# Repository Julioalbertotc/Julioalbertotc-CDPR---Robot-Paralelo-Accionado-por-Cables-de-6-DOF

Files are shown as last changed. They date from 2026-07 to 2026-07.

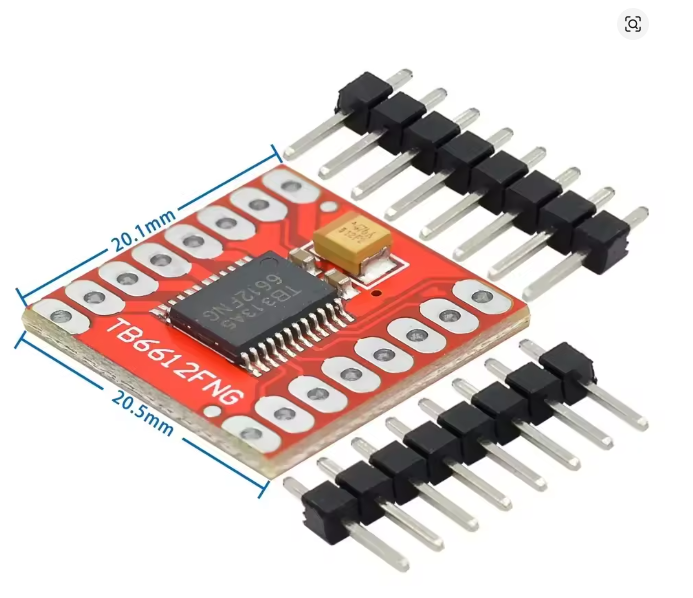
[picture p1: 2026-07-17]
robot de cables/Documentation_Parts/Documentation_Bridge-H/Measures_Bridge-H.png

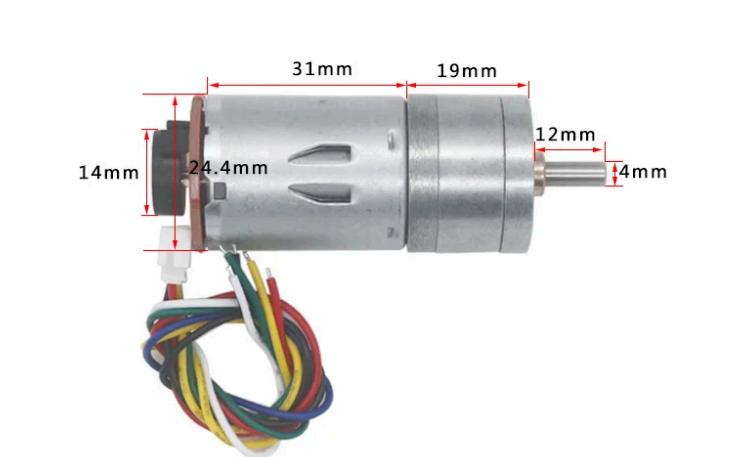
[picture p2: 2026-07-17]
robot de cables/Documentation_Parts/Documentacion_Motores/Engine_Measurements.png

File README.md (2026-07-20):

# CDPR — Robot Paralelo Accionado por Cables de 6-DOF
## Arquitectura Simétrica Dual ESP32 · Control GPIO Nativo · Sin Expansor de Pines





Este repositorio contiene el firmware definitivo y funcional para un **Robot Paralelo Accionado por Cables (CDPR)** de **8 cables** y **6 grados de libertad** (X, Y, Z, Roll, Pitch, Yaw). La arquitectura de control distribuye la carga de I/O de forma completamente simétrica en **dos módulos ESP32 idénticos** interconectados por UART a alta velocidad, eliminando completamente cualquier necesidad de expansor de pines externo (I2C, SPI, MCP23017 o similar).

---

## 2. Arquitectura General

El sistema emplea dos ESP32 en roles complementarios pero con **hardware idéntico** en cada uno:

- **ESP32 MAIN (Maestro):** Gestiona localmente los **Motores 0–3** (PWM `ledc` + dirección GPIO + encoder `PCNT`). Centraliza el **lazo de control PID a 1 kHz** para los 8 motores. Aloja la interfaz web/WebSocket, la API JSON-Serial para PC y calcula la **cinemática inversa 6-DOF**.
- **ESP32 SUB/ENCODER (Esclavo):** Gestiona localmente los **Motores 4–7** (PWM `ledc` + dirección GPIO + encoder `PCNT`). Recibe las consignas de PWM calculadas por el Maestro y le retransmite el conteo de sus encoders físicos. En `SIMULATION_MODE=1`, integra la dinámica eléctrica del motor DC por software y genera encoders virtuales para pruebas sin hardware.

Ambas placas se interconectan por **UART2 a 921600 bps** con protocolo binario y verificación de integridad **CRC8 Dallas/Maxim**.

> [!IMPORTANT]
> **Control 100% nativo por GPIO:** No se usa ningún expansor de pines I2C (MCP23017 ni equivalente). Todo el control de PWM se realiza con el módulo `ledc` del ESP32 y la lectura de encoders con el periférico de hardware `PCNT` — todo directamente en los pines GPIO de cada placa.

### Diagrama de Flujo de Datos

```mermaid
graph TD
    subgraph SUB ["ESP32 SUB (Esclavo) — Motores 4–7"]
        EncS["Encoders físicos M4–M7\nGPIO 34,35 / 36,39 / 32,33 / 21,22"]
        PCNTS["Contadores PCNT Hardware\nUnidades 0–3"]
        DriversS["Drivers TB6612FNG\nPWM ledc + IN1/IN2"]
    end

    subgraph MAIN ["ESP32 MAIN (Maestro) — Motores 0–3"]
        EncM["Encoders físicos M0–M3\nGPIO 34,35 / 36,39 / 32,33 / 21,22"]
        PCNTM["Contadores PCNT Hardware\nUnidades 0–3"]
        DriversM["Drivers TB6612FNG\nPWM ledc + IN1/IN2"]
        PID["Lazo PID Centralizado\n1 kHz — 8 motores\nKp=8.5 Ki=0.1 Kd=0.4"]
        Kin["Cinemática Inversa 6-DOF\nR_zyx · 8 cables"]
        EncM --> PCNTM
        PCNTM -->|"ticks locales 0–3"| PID
        PID --> DriversM
        PID --> Kin
    end

    EncS --> PCNTS
    PCNTS -->|"UART2 SOF:0xAA0xBB\nTelemetría encoders 4–7\n38 bytes · 1 kHz · CRC8"| PID
    PID -->|"UART2 SOF:0xCC0xDD\nConsignas PWM M0–M7\n37 bytes · 1 kHz · CRC8"| DriversS

    Web["Interfaz Web\nWiFi AP · WebSocket"] <-->|"Pose / Estado"| MAIN
    PC["PC / Python Sim\nJSON-Serial 115200"] <-->|"cmd pose / homing / estop"| MAIN
```

> [!NOTE]
> En `SIMULATION_MODE=1` (por defecto en `firmware-encoder/platformio.ini`), el ESP32 SUB simula la física del motor DC internamente y genera encoders virtuales, permitiendo validar el lazo de control completo sin conectar ningún motor real.

---

## 3. Tabla Completa de Asignación de Pines

> [!WARNING]
> Ambas placas utilizan **exactamente los mismos números de GPIO** para sus motores locales (son dos chips físicos distintos). Etiquetar físicamente cada placa y cada grupo de cables es **crítico** para evitar cablear los motores a la placa incorrecta.

### Placa 1 — ESP32 MAIN (Maestro) · Motores 0–3

| Motor | PWM (ledc) | IN1 | IN2 | Enc A | Enc B | Unidad PCNT | Nota |
|:---|:---|:----|:----|:---|:---|:---|:-----|
| **M0** | GPIO **2** | GPIO 4 | GPIO **15** | GPIO **34** | GPIO **35** | PCNT 0 | GPIO 2 y 15: strapping pins |
| **M1** | GPIO **12** | GPIO 13 | GPIO 14 | GPIO **36** | GPIO **39** | PCNT 1 | GPIO 12: strapping (MTDI) |
| **M2** | GPIO 25 | GPIO 26 | GPIO 27 | GPIO 32 | GPIO 33 | PCNT 2 | GPIO estándar |
| **M3** | GPIO 18 | GPIO 19 | GPIO 23 | GPIO 21 | GPIO 22 | PCNT 3 | GPIO estándar |

### Placa 2 — ESP32 SUB (Esclavo) · Motores 4–7

| Motor | PWM (ledc) | IN1 | IN2 | Enc A | Enc B | Unidad PCNT | Nota |
|:---|:---|:----|:----|:---|:---|:---|:-----|
| **M4** | GPIO **2** | GPIO 4 | GPIO **15** | GPIO **34** | GPIO **35** | PCNT 0 | GPIO 2 y 15: strapping pins |
| **M5** | GPIO **12** | GPIO 13 | GPIO 14 | GPIO **36** | GPIO **39** | PCNT 1 | GPIO 12: strapping (MTDI) |
| **M6** | GPIO 25 | GPIO 26 | GPIO 27 | GPIO 32 | GPIO 33 | PCNT 2 | GPIO estándar |
| **M7** | GPIO 18 | GPIO 19 | GPIO 23 | GPIO 21 | GPIO 22 | PCNT 3 | GPIO estándar |

### Pines de Sistema (Idénticos en Ambas Placas)

| Función | GPIO | Dirección | Descripción |
|:---|:-----|:---|:---|
| **STBY local** | **5** | Salida | LOW apaga instantáneamente los 4 canales TB6612FNG locales. Strapping pin — seguro gracias al pull-down interno del TB6612. |
| **UART2 RX** | **16** | Entrada | Recepción del bus de interconexión. Cruzar con TX de la otra placa. |
| **UART2 TX** | **17** | Salida | Transmisión del bus de interconexión. Cruzar con RX de la otra placa. |
| **UART0 TX** | **1** | Salida | Debug / consola serial por USB (UART0). |
| **UART0 RX** | **3** | Entrada | Debug / consola serial por USB (UART0). |

### Notas Críticas sobre Pines Especiales

> [!TIP]
> **Strapping pins (2, 5, 12, 15):** Estos cuatro GPIO determinan el modo de arranque del ESP32. Su uso como salidas de control es seguro en este diseño porque el integrado **TB6612FNG** incorpora resistencias internas de pull-down débil (~200 kΩ) en todos sus pines de entrada (PWM, IN1, IN2, STBY). Esto mantiene las líneas en nivel `LOW` durante el arranque, garantizando el modo de ejecución `SPI Flash Standard` sin componentes de pull-down adicionales en la PCB.

> [!NOTE]
> **Pines input-only (34, 35, 36, 39):** No tienen transistores de salida ni resistencias internas de pull-up/pull-down. Se usan exclusivamente como entradas para los canales A y B de los encoders ópticos de los motores M0/M1 (o M4/M5 en el SUB), donde las señales activas provienen del encoder sin necesidad de pull-up interno.

---

## 4. Protocolo de Comunicación UART

El bus de interconexión opera de forma ininterrumpida a **921600 bps** (`SERIAL_8N1`) sobre `Serial2` en ambas placas (GPIO 16 RX / GPIO 17 TX, **cruzado** entre las dos). El protocolo es **binario compacto** con verificación de integridad por **CRC8 Dallas/Maxim (polinomio reflejado 0x8C)**.

### Trama 1: Telemetría de Encoders `SUB → MAIN` (38 bytes, 1 kHz)

| Bytes | Campo | Valor / Descripción |
|:---|:---|:---|
| 0–1 | `SOF` | `0xAA 0xBB` (Start-Of-Frame) |
| 2 | `LENGTH` | `0x20` (32 bytes de payload) |
| 3 | `SEQ` | Contador circular 0–255 para detección de frames perdidos |
| 4 | `BOOT_ID` | ID pseudoaleatorio (`esp_random()`) generado en cada arranque del SUB para detectar reinicios inesperados |
| 5–36 | `PAYLOAD` | `int32_t[8]` — conteo acumulado de encoders. Índices 0–3 = 0 (remoto), índices 4–7 = conteo físico local de M4–M7 |
| 37 | `CRC8` | CRC8 calculado sobre bytes [3..36] (SEQ + BOOT_ID + PAYLOAD) |

### Trama 2: Consignas de Control `MAIN → SUB` (37 bytes, 1 kHz)

| Bytes | Campo | Valor / Descripción |
|:---|:---|:---|
| 0–1 | `SOF` | `0xCC 0xDD` (Start-Of-Frame) |
| 2 | `LENGTH` | `0x20` (32 bytes de payload) |
| 3 | `SEQ` | Contador circular 0–255 |
| 4–35 | `PAYLOAD` | `float[8]` — PWM con signo de –255.0 a +255.0 para cada motor (calculado por el PID centralizado) |
| 36 | `CRC8` | CRC8 calculado sobre bytes [3..35] (SEQ + PAYLOAD) |

### Timeout de Seguridad Distribuido (ESTOP Autónomo)

Ambas placas implementan su propio watchdog de comunicación de forma **completamente independiente** — ninguna depende de la otra para entrar en modo seguro:

- **ESP32 MAIN:** Si no recibe telemetría válida en más de **50 ms**, entra en `STATE_ESTOP` localmente: tira su `STBY` a `LOW`, fija el target de cada motor en su posición actual y apaga todas las salidas PWM locales (M0–M3).
- **ESP32 SUB:** Si no recibe consignas válidas en más de **50 ms**, desactiva su `STBY` local a `LOW` y apaga PWM + IN1/IN2 de todos sus motores locales (M4–M7) de forma autónoma, sin esperar ninguna orden de la placa MAIN.

---

## 5. Sistema de Control (PID)

El lazo de posición se calcula de forma **centralizada en el ESP32 MAIN** para los **8 motores simultáneamente** a una frecuencia de **1 kHz** en el Core 0 (`controlLoopTask`). El estado combinado —encoders locales leídos por PCNT + encoders remotos recibidos por UART— se fusiona en cada iteración.

### Parámetros del Controlador (definidos en `Config.h`)

| Parámetro | Valor | Descripción |
|:---|:---|:---|
| `PID_KP` | **8.5** | Ganancia proporcional |
| `PID_KI` | **0.1** | Ganancia integral |
| `PID_KD` | **0.4** | Ganancia derivativa |
| `PID_INTEGRAL_LIMIT` | **±50.0** | Límite anti-windup (clamp simétrico) |
| `PID_MAX_PWM` | **255** | Límite superior de salida |
| `PID_MIN_PWM` | **–255** | Límite inferior de salida |
| `HOLDING_TORQUE_PWM` | **25** | Pre-tensión mínima aplicada en reposo |

### Lógica de Actuación

- **Torque de retención activo (anti-holgura):** Cuando la señal PID es positiva pero menor que `HOLDING_TORQUE_PWM`, se satura a 25 para mantener tensión mínima en el cable y evitar holguras. Si el error es pequeño (< 50 ticks ≈ 1.5 mm) y la señal sería negativa, también se aplica la pre-tensión positiva.
- **Freno activo (Short-Brake):** Cuando `pwm_output == 0`, ambos pines de dirección (`IN1=LOW`, `IN2=LOW`) generan un cortocircuito dinámico en el devanado del motor para frenado instantáneo.
- **ESTOP por hardware:** En `STATE_ESTOP`, el pin `STBY` se tira a `LOW` en hardware deshabilitando el driver TB6612FNG antes de que cualquier señal de software llegue al motor.

---

## 6. Cinemática Inversa

El modelo cinemático transforma la **pose del efector final** (X, Y, Z, Roll, Pitch, Yaw) en la **longitud de los 8 cables** requerida para alcanzarla:

```
L_i = || P_i - (X_ef + R_zyx * a_i) ||_2
```

Donde:
- `P_i` — Posición de la polea fija i en el marco del mundo (`POLE_POSITIONS`, en centímetros).
- `a_i` — Punto de anclaje en la plataforma móvil (`ANCHOR_POSITIONS`, relativo al centro del efector).
- `R_zyx` — Matriz de rotación intrínseca Rz(yaw) · Ry(pitch) · Rx(roll).

### Parámetros Geométricos (Config.h / kinematics.py)

| Cable | POLE_POSITIONS [cm] | ANCHOR_POSITIONS [cm] |
|:---|:---|:---|
| 0 | (−22.5, −21.0, 45.0) | (−5.0, −4.0, 0.0) |
| 1 | (−21.0, −22.5, 45.0) | (−4.0, −5.0, 0.0) |
| 2 | (+21.0, −22.5, 45.0) | (+4.0, −5.0, 0.0) |
| 3 | (+22.5, −21.0, 45.0) | (+5.0, −4.0, 0.0) |
| 4 | (+22.5, +21.0, 45.0) | (+5.0, +4.0, 0.0) |
| 5 | (+21.0, +22.5, 45.0) | (+4.0, +5.0, 0.0) |
| 6 | (−21.0, +22.5, 45.0) | (−4.0, +5.0, 0.0) |
| 7 | (−22.5, +21.0, 45.0) | (−5.0, +4.0, 0.0) |

**Pose inicial por defecto:** X=0, Y=0, Z=22.5 cm, Roll=0, Pitch=0, Yaw=0.

**Implementaciones del modelo:**
- Firmware C++: `firmware-main/src/Kinematics.cpp` y `Kinematics.h`
- Validación Python: `python-sim/kinematics.py`

---

## 7. Estructura del Repositorio

```
codigo/
├── README.md                      <- Este archivo (fuente de verdad del proyecto)
│
├── firmware-main/                 # Proyecto PlatformIO — ESP32 MAIN (Maestro)
│   ├── platformio.ini             # Plataforma pioarduino 51.03.07, SIMULATION_MODE=0
│   ├── data/                      # Archivos de interfaz web (HTML/CSS/JS) → LittleFS
│   └── src/
│       ├── Config.h               # Pines M0–M3, constantes PID, geometría del robot
│       ├── Kinematics.cpp / .h    # Cinemática inversa 6-DOF (R_zyx, 8 cables)
│       ├── MotorController.cpp    # Lazo PID, torque retención, freno activo, GPIO
│       ├── MotorController.h      # Interfaz pública del controlador de motor
│       ├── Globals.cpp / .h       # Variables de estado global compartidas entre archivos
│       ├── SystemState.h          # Enum de estados: UNHOMED, HOMING, READY, ESTOP
│       ├── WebInterface.h         # Servidor AsyncWeb + WebSocket (telemetría 20 Hz)
│       └── main.cpp               # Setup Core 1, controlLoopTask Core 0 a 1 kHz,
│                                  #   PCNT local, parser UART no bloqueante, JSON-Serial
│
├── firmware-encoder/              # Proyecto PlatformIO — ESP32 SUB (Esclavo)
│   ├── platformio.ini             # Plataforma pioarduino 51.03.07, SIMULATION_MODE=1
│   └── src/
│       ├── Config.h               # Pines M4–M7, constantes de simulación de motor DC
│       └── main.cpp               # encoderTask Core 1 a 1 kHz, PCNT, UART,
│                                  #   GPIO físico M4–M7, simulación DC por software
│
├── python-sim/                    # Scripts Python para validación y visualización en PC
│   ├── kinematics.py              # Espejo Python del modelo cinemático del firmware
│   ├── motor_sim.py               # Simulación dinámica auxiliar del motor DC
│   ├── validation.py              # Test de validación cruzada: Python vs ESP32 via serial
│   └── visualizer.py             # Visualizador gráfico de pose y longitudes de cable
│
└── docs/                          # Documentación técnica adicional
    ├── README.md                  # Copia de referencia de este README
    └── pin_audit_report.md        # Reporte detallado de auditoría de conflictos de pines
```

---

## 8. Cómo Compilar y Flashear

### Requisitos

- **VS Code** con la extensión **PlatformIO IDE** instalada.
- **Plataforma ESP32:** `pioarduino/platform-espressif32` versión `51.03.07` (se descarga automáticamente al compilar).
- **Framework:** Arduino Core para ESP32 (gestionado por PlatformIO).

### Compilar y Flashear el ESP32 MAIN (Maestro)

```bash
# Desde la subcarpeta firmware-main/
cd firmware-main

# Solo compilar (verificar que no hay errores):
pio run

# Compilar y flashear el firmware (placa MAIN conectada por USB):
pio run --target upload

# Subir la interfaz web al sistema de archivos LittleFS:
pio run --target uploadfs

# Monitorear salida serial a 115200 bps:
pio device monitor
```

### Compilar y Flashear el ESP32 SUB (Esclavo)

```bash
# Desde la subcarpeta firmware-encoder/
cd firmware-encoder

# Compilar y flashear (placa SUB conectada por USB):
pio run --target upload

# Monitorear salida serial del SUB:
pio device monitor
```

> [!NOTE]
> Si tienes ambas placas conectadas simultáneamente, especifica el puerto con `--upload-port COMx` para evitar flashear la placa incorrecta.

### Selección de Modo: Físico vs Simulación

| Flag | `SIMULATION_MODE=0` | `SIMULATION_MODE=1` |
|:-----|:---|:---|
| **Encoders SUB** | Leídos desde hardware PCNT físico | Integración numérica de motor DC por software |
| **PWM/Dir SUB** | Aplicados a GPIO físicos + TB6612FNG | No se escribe ningún GPIO de potencia |
| **PCNT MAIN** | Leídos desde hardware PCNT físico | Se usan los ticks virtuales recibidos por UART |
| **Uso recomendado** | Hardware completo conectado | Pruebas de lazo de control sin motores |

Para alternar entre modos, editar en `platformio.ini` del proyecto correspondiente:

```ini
build_flags =
    -DSIMULATION_MODE=0   ; Modo físico real
    ; -DSIMULATION_MODE=1 ; Modo simulación (comentar la línea de arriba)
```

---

## 9. Cómo Correr el Simulador Python

El script `python-sim/validation.py` envía una secuencia de 9 poses de prueba al ESP32 MAIN por JSON-Serial y compara las longitudes de cable calculadas en Python contra las calculadas por el firmware, con tolerancia de 0.01 cm (0.1 mm).

### Requisitos Python

```bash
pip install pyserial
```

### Ejecución

1. Conectar el ESP32 MAIN al PC por USB.
2. Editar la constante `PORT` al inicio de `validation.py` según el puerto asignado:
   ```python
   PORT = 'COM5'   # Windows: 'COMx'  |  Linux/macOS: '/dev/ttyUSB0'
   ```
3. Ejecutar el script desde la carpeta `codigo/`:
   ```bash
   python python-sim/validation.py
   ```
4. El script envía primero un comando de homing y luego itera por las poses de prueba, reportando la diferencia máxima por cable en cada iteración.

> [!TIP]
> Si no hay ningún ESP32 conectado, el script entra en **modo offline** y valida únicamente las matemáticas de `kinematics.py` contra los resultados teóricos, sin requerir hardware.

Otros scripts disponibles:
- `motor_sim.py` — Simulación dinámica autónoma del motor DC con respuesta en bucle abierto.
- `visualizer.py` — Representación gráfica en tiempo real de la pose y longitudes de cable.

---

## 10. Advertencias de Hardware Críticas

> [!CAUTION]
> **GND Común Obligatorio entre Placas:** El bus de interconexión UART opera a 921600 bps. Sin una referencia de tierra compartida entre ambas placas, los niveles lógicos se vuelven indefinidos, causando corrupción permanente de tramas y activación constante del `STATE_ESTOP`. Conectar físicamente los pines `GND` de ambas placas entre sí **antes** de conectar cualquier línea UART.

> [!CAUTION]
> **No Confundir Cableado entre Placas:** Ambas placas usan los mismos números de GPIO para sus motores locales (son dos chips distintos). Un error de cableado puede resultar en un lazo de control cerrado sobre el encoder equivocado. **Etiquetar físicamente cada placa** como `MAIN (M0–M3)` y `SUB (M4–M7)` y marcar cada grupo de cables con colores distintos.

> [!WARNING]
> **Arranque Incremental Seguro — Primera Puesta en Marcha:** Alimentar las placas ESP32 por USB primero, **con la línea de 12V de los motores desconectada**. Verificar en el monitor serial que: (1) ambas placas inicializan sin errores, (2) el MAIN reporta frames de telemetría fluyendo sin caer en ESTOP por timeout, y (3) el contador `dropped_frames` se mantiene bajo o en cero. Solo entonces conectar la alimentación de 12V a los TB6612FNG.

> [!WARNING]
> **UART2 TX/RX Cruzados:** Las líneas UART2 deben ir **cruzadas**: `GPIO 17 (TX)` del MAIN conecta a `GPIO 16 (RX)` del SUB, y `GPIO 16 (RX)` del MAIN conecta a `GPIO 17 (TX)` del SUB. Una conexión directa (no cruzada) resulta en comunicación unidireccional silenciosa y activación inmediata del timeout de ESTOP.

> [!WARNING]
> **Strapping Pins durante el Primer Flasheo:** Los GPIOs 2, 5, 12 y 15 determinan el modo de arranque del ESP32. Si alguno de estos pines está en alto durante el reset (por ejemplo, si el motor o encoder está conectado y activo), el ESP32 puede arrancar en modo incorrecto. Desconectar los drivers durante el primer flasheo.

> [!NOTE]
> **Detección Automática de Reinicio del SUB (BOOT_ID):** El `BOOT_ID` aleatorio incluido en cada trama de telemetría permite al MAIN detectar si el SUB se reinició inesperadamente durante la operación (`STATE_READY`). Ante un cambio de `BOOT_ID`, el MAIN fuerza inmediatamente `STATE_ESTOP` para prevenir pérdida de referencia de posición.

---

## 11. Estado del Proyecto / Roadmap

### Hito Actual ✅

- Arquitectura dual ESP32 completamente definida, compilando sin errores en ambos firmwares.
- Protocolo UART binario con CRC8, BOOT_ID y detección de frames perdidos implementado.
- Lazo PID centralizado a 1 kHz con anti-windup (±50), torque de retención (PWM=25) y freno activo.
- Cinemática inversa 6-DOF (R_zyx) validada cruzando Python contra firmware con tolerancia 0.01 cm.
- `SIMULATION_MODE=1` operativo: lazo cerrado completo validable sin hardware de motores.
- Interfaz web / WebSocket con telemetría a 20 Hz y API JSON-Serial para control desde PC.
- ESTOP distribuido: timeout autónomo de 50 ms en ambas placas sin dependencia entre sí.

### Próximos Pasos 🔜

- Validación hardware en banco con motores DC reales y encoders ópticos físicos.
- Calibración de Kp, Ki, Kd en lazo cerrado real.
- Ajuste de la geometría (POLE_POSITIONS / ANCHOR_POSITIONS) a la estructura física construida.
- Implementación de límites de workspace y detección de singularidades cinemáticas.
- Logging de datos de control a SD card o buffer circular para análisis post-run.

> Para el seguimiento detallado de tareas y decisiones de diseño, ver la carpeta `docs/` y las notas de Obsidian del proyecto.

---

## 12. Licencia

Este proyecto está licenciado bajo la **MIT License** — libre de usar, modificar y distribuir con atribución.

```
MIT License
Copyright (c) 2026 — CDPR Project
```

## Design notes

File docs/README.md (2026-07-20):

# CDPR - Robot Paralelo Accionado por Cables de 6-DOF
## Arquitectura Simétrica Dual ESP32 (Sin Expansor de Pines)




Este repositorio contiene la arquitectura de control y firmware definitiva para un Robot Paralelo Accionado por Cables (CDPR - Cable-Driven Parallel Robot) de 6 grados de libertad (X, Y, Z, Roll, Pitch, Yaw). La plataforma física emplea 8 cables de tracción independientes accionados por motores DC con encoders ópticos de cuadratura y controladores de potencia TB6612FNG.

La arquitectura de hardware elimina la necesidad de expansores de pines externos (como el MCP23017), distribuyendo la carga de I/O de manera balanceada y simétrica en **dos módulos ESP32 interconectados**.

---

## 2. Arquitectura General

El sistema distribuye el control y la lectura física de forma simétrica entre las dos placas:
*   **ESP32 MAIN (Maestro):** Gestiona los **Motores 0 a 3** (PWM, dirección y encoders) de manera local. Además de su rol local, centraliza el lazo de control PID a 1 kHz, calcula la cinemática inversa y aloja la interfaz web/WebSocket y la API de comunicación JSON Serial para la PC.
*   **ESP32 SUB/ENCODER (Esclavo):** Gestiona los **Motores 4 a 7** (PWM, dirección y encoders) de manera local. Recibe las consignas de PWM desde el Maestro y le transmite el conteo físico de sus encoders a través de una comunicación UART de alta velocidad a 921600 bps.

```mermaid
graph TD
    %% Bloques de Entrada y Lectura de Encoders
    subgraph ESP32_SUB [ESP32 SUB / ESCLAVO]
        EncS[Encoders Locales M4-M7] -->|Hardware PCNT| CntS[Conteo de Encoders 4-7]
        ActS[Actuadores Locales M4-M7]
        StbyS[STBY local]
    end

    subgraph ESP32_MAIN [ESP32 MAIN / MAESTRO]
        EncM[Encoders Locales M0-M3] -->|Hardware PCNT| CntM[Conteo de Encoders 0-3]
        ActM[Actuadores Locales M0-M3]
        StbyM[STBY local]
        
        %% Bloque de Control PID
        PID[Lazo de Control PID Centralizado 1kHz]
        Kin[Cinemática Inversa 6-DOF]
    end

    %% Flujo UART
    CntS -->|UART2: Telemetría Encoders 4-7| PID
    PID -->|Cálculo Cinemático| Kin
    PID -->|Aplicación Directa| ActM
    PID -->|UART2: Consignas PWM M4-M7| ActS

    %% Servidores e Interfaces
    Web[Interfaz Web / WebSockets] <-->|Comandos y Estado| ESP32_MAIN
    PC[PC / Python Simulator] <-->|JSON Serial| ESP32_MAIN
```

> [!IMPORTANT]
> **Control 100% Nativo:** Este diseño prescinde por completo de expansores I2C (como el MCP23017) o periféricos externos. Toda la señalización se genera a nivel de registros GPIO nativos utilizando los recursos internos del microcontrolador (módulos de PWM `ledc` y contadores de pulsos `PCNT`).

---

## 3. Tabla Completa de Asignación de Pines

Dado que el diseño es simétrico, ambas placas se conectan eléctricamente a sus respectivos componentes usando la misma matriz de pines. **Es estrictamente recomendable etiquetar físicamente cada placa para evitar confusiones de cableado.**

### Placa 1: ESP32 MAIN (Maestro) - Motores 0 a 3
| Canal Lógico | PWM Pin | IN1 | IN2 | Enc A | Enc B | Unidad PCNT | Notas / Strapping |
| :--- | :--- | :--- | :--- | :--- | :--- | :--- | :--- |
| **Motor 0 (M0)** | GPIO 2 | GPIO 4 | GPIO 15 | GPIO 34 | GPIO 35 | PCNT 0 | GPIO 2 y 15 son Strapping |
| **Motor 1 (M1)** | GPIO 12 | GPIO 13 | GPIO 14 | GPIO 36 | GPIO 39 | PCNT 1 | GPIO 12 es Strapping (MTDI) |
| **Motor 2 (M2)** | GPIO 25 | GPIO 26 | GPIO 27 | GPIO 32 | GPIO 33 | PCNT 2 | GPIO estándar |
| **Motor 3 (M3)** | GPIO 18 | GPIO 19 | GPIO 23 | GPIO 21 | GPIO 22 | PCNT 3 | GPIO estándar |

### Placa 2: ESP32 SUB (Esclavo) - Motores 4 a 7
| Canal Lógico | PWM Pin | IN1 | IN2 | Enc A | Enc B | Unidad PCNT | Notas / Strapping |
| :--- | :--- | :--- | :--- | :--- | :--- | :--- | :--- |
| **Motor 4 (M4)** | GPIO 2 | GPIO 4 | GPIO 15 | GPIO 34 | GPIO 35 | PCNT 0 | GPIO 2 y 15 son Strapping |
| **Motor 5 (M5)** | GPIO 12 | GPIO 13 | GPIO 14 | GPIO 36 | GPIO 39 | PCNT 1 | GPIO 12 es Strapping (MTDI) |
| **Motor 6 (M6)** | GPIO 25 | GPIO 26 | GPIO 27 | GPIO 32 | GPIO 33 | PCNT 2 | GPIO estándar |
| **Motor 7 (M7)** | GPIO 18 | GPIO 19 | GPIO 23 | GPIO 21 | GPIO 22 | PCNT 3 | GPIO estándar |

### Pines de Sistema por Placa:
*   **STBY Local:** `GPIO 5` (Salida digital, una en cada placa. Al ponerse en `LOW` deshabilita de inmediato sus 4 canales de potencia TB6612 locales).
*   **Interconexión UART2:** `GPIO 16` (RX) y `GPIO 17` (TX). *Las líneas deben ir cruzadas (TX de MAIN a RX de SUB y viceversa).*
*   **Depuración/Carga UART0:** `GPIO 1` (TX) y `GPIO 3` (RX), enrutados a través del puerto Micro-USB/USB-C UART de la placa.

### Notas Críticas de Diseño:
> [!TIP]
> **Seguridad de Strapping Pins (2, 5, 12, 15):** Estos pines determinan el modo de arranque del ESP32. Su uso es seguro en este diseño ya que todas las entradas del integrado TB6612FNG (PWM, IN1, IN2, STBY) poseen resistencias internas de pulldown débiles de ~200k. Esto mantiene las señales en nivel `LOW` durante el arranque, asegurando el modo de ejecución SPI estándar de la Flash sin componentes de pull-down adicionales.
>
> **Entradas Restringidas (Input-Only):** Los pines `34, 35, 36 y 39` no tienen transistores de salida y carecen de pull-ups/pull-downs internos. Su uso exclusivo como entradas para los canales de encoders A/B de los motores 0 y 1 (o 4 y 5) es ideal debido a que los encoders ópticos envían pulsos activos definidos externamente.

---

## 4. Protocolo de Comunicación UART

La comunicación binaria de interconexión corre de manera ininterrumpida en Core 1 a 921600 bps. Emplea tramas compactas con verificación de integridad por hardware mediante el polinomio **CRC8 Dallas/Maxim (0x31)**.

### Tipos de Tramas:
1.  **Telemetría de Encoders (SUB -> MAIN, 38 bytes, 1 kHz):**
    *   `SOF 1 & 2`: `0xAA 0xBB`
    *   `LENGTH`: `0x20` (32 bytes)
    *   `SEQ`: Contador circular de secuencia (0-255).
    *   `BOOT_ID`: Identificador pseudoaleatorio generado al iniciar el esclavo para verificar fallos de alimentación remotos.
    *   `PAYLOAD`: `int32_t[8]` con el conteo acumulado de encoders (los índices 4-7 contienen el conteo de M4-M7; los índices 0-3 se transmiten en 0).
    *   `CRC8`: Byte de verificación.
2.  **Consignas de Control (MAIN -> SUB, 37 bytes, 1 kHz):**
    *   `SOF 1 & 2`: `0xCC 0xDD`
    *   `LENGTH`: `0x20` (32 bytes)
    *   `SEQ`: Contador circular.
    *   `PAYLOAD`: `float[8]` con los ciclos de PWM con signo (`-255.0` a `255.0`) calculados por el PID.
    *   `CRC8`: Byte de verificación.

### Timeout de Seguridad Distribuido (ESTOP):
*   Si el **ESP32 MAIN** no recibe telemetría válida por más de **50 ms**, ingresa localmente en `STATE_ESTOP`, apaga sus salidas PWM locales y tira su `STBY` a `LOW`.
*   Si el **ESP32 SUB** no recibe consignas válidas por más de **50 ms**, desactiva localmente su pin `STBY` y apaga todas las salidas de dirección (`IN1`/`IN2`) y PWM a sus motores locales de forma autónoma.

---

## 5. Sistema de Control (PID)

El lazo PID de posición se calcula de forma centralizada en el ESP32 MAIN a **1 kHz**:
*   **Ganancias:** $K_p = 8.5$, $K_i = 0.1$, $K_d = 0.4$.
*   **Anti-Windup:** Límite integral de $\pm 50.0$.
*   **Freno Activo (Short-Brake):** Al detenerse o ante consignas nulas, las señales del driver se ponen en `IN1=LOW` e `IN2=LOW`, forzando el cortocircuito dinámico del motor para frenado instantáneo.
*   **Torque de Retención Activo:** Para eliminar holguras indeseadas en los cables de tracción, el controlador inyecta una pre-tensión constante equivalente a un PWM mínimo de `25` en reposo cerca de la pose objetivo.

---

## 6. Cinemática Inversa

El robot controla la pose del efector final en un espacio de 6 grados de libertad. El modelo cinemático transforma la coordenada del efector $(X, Y, Z, Roll, Pitch, Yaw)$ a la longitud correspondiente de los 8 cables de soporte:
$$L_i = \| \mathbf{P}_i - (\mathbf{X}_{ef} + \mathbf{R}_{zyx} \mathbf{a}_i) \|$$
Donde:
*   $\mathbf{P}_i$ representa las coordenadas del anclaje superior de la polea $i$ (definidas en `POLE_POSITIONS`).
*   $\mathbf{a}_i$ representa el punto de anclaje en el efector final de la plataforma (definidas en `ANCHOR_POSITIONS`).
*   $\mathbf{R}_{zyx}$ es la matriz de rotación del efector final.

El cálculo completo en punto flotante se ejecuta en el procesador Maestro y puede consultarse en [Kinematics.cpp](file:///c:/Users/julio/Desktop/robot%20de%20cables/Cable-Driven%20Parallel%20Robot/codigo/firmware-main/src/Kinematics.cpp).

---

## 7. Estructura del Repositorio

```text
codigo/
├── docs/                         # Documentación del hardware y reportes de auditoría
│   ├── README.md                 # Copia de este README
│   └── pin_audit_report.md       # Reporte detallado de la auditoría de pines original
├── firmware-main/                # Proyecto PlatformIO para el ESP32 Maestro (MAIN)
│   ├── src/
│   │   ├── Config.h              # Mapeo de pines de M0-M3 y configuraciones
│   │   ├── Kinematics.cpp / .h   # Cinemática inversa 6-DOF
│   │   ├── MotorController.cpp   # Control PID y GPIO de motores locales
│   │   ├── Globals.cpp / .h      # Variables de estado global compartidas
│   │   └── main.cpp              # Lazo a 1 kHz, PCNT local y parseador UART
│   ├── platformio.ini            # Configuración de compilación para el Maestro
│   └── data/                     # Archivos de interfaz web (HTML/CSS/JS) para LittleFS
├── firmware-encoder/             # Proyecto PlatformIO para el ESP32 Esclavo (SUB)
│   ├── src/
│   │   ├── Config.h              # Mapeo de pines de M4-M7 locales
│   │   └── main.cpp              # PCNT esclavo, UART y salidas GPIO físicas
│   └── platformio.ini            # Configuración de compilación para el Esclavo
└── python-sim/                   # Scripts de visualización y pruebas de la PC
    ├── validation.py             # Script principal de validación serial JSON
    └── motor_sim.py              # Script auxiliar de prueba y simulación
```

---

## 8. Cómo Compilar y Flashear

### Requisitos:
*   VS Code con la extensión **PlatformIO IDE**.
*   Framework Arduino para ESP32 (Core v3.x o superior).

### Instrucciones de Carga:

1.  **Cargar el ESP32 MAIN (Maestro):**
    *   Conecta la placa MAIN por USB.
    *   Abre la carpeta `firmware-main/` en VS Code.
    *   Compila y carga el firmware:
        ```bash
        pio run --target upload
        ```
    *   Sube la interfaz web al sistema de archivos LittleFS:
        ```bash
        pio run --target uploadfs
        ```
2.  **Cargar el ESP32 SUB (Esclavo):**
    *   Conecta la placa SUB por USB.
    *   Abre la carpeta `firmware-encoder/` en VS Code.
    *   Compila y carga el firmware:
        ```bash
        pio run --target upload
        ```

### Selección de Modo Físico vs Simulación:
En el archivo `Config.h` de ambos proyectos, puedes alterar el comportamiento general alternando el flag `SIMULATION_MODE`:
*   `#define SIMULATION_MODE 0` -> Modo físico real conectado a drivers y encoders.
*   `#define SIMULATION_MODE 1` -> Modo simulación (el ESP32 SUB simula la respuesta inercial del motor DC internamente por software).

---

## 9. Cómo Correr el Simulador Python

El script de validación en Python permite interactuar con el robot enviándole comandos de pose en formato JSON a través del puerto serie USB de la PC conectada al ESP32 Maestro:

1.  Instala las dependencias en la terminal de tu PC:
    ```bash
    pip install pyserial
    ```
2.  Ejecuta el script indicando el puerto COM donde se encuentra el ESP32 MAIN:
    ```bash
    python python-sim/validation.py
    ```

---

## 10. Advertencias de Hardware Críticas

> [!CAUTION]
> **Tierra Común Obligatoria:** El bus de interconexión UART opera a alta frecuencia (921600 bps). Es estrictamente obligatorio conectar físicamente las líneas `GND` de ambos ESP32. La falta de una referencia común provocará la corrupción de datos y activará constantemente el timeout de parada de emergencia (`STATE_ESTOP`).
>
> **Encendido Incremental Seguro:** Durante la primera puesta en marcha, se recomienda alimentar las placas ESP32 por USB y mantener la línea de potencia del motor (VM) apagada. Verifica en el monitor serial que las comunicaciones fluyan sin activar el ESTOP antes de alimentar las etapas de potencia (12V).
>
> **Errores de Conexión Cruzada:** Ambas placas usan internamente la misma numeración de pines GPIO para motores y encoders. Etiqueta físicamente los cables "GRUPO MAIN (M0-M3)" y "GRUPO SUB (M4-M7)" para evitar aplicar señales de control a la placa equivocada.

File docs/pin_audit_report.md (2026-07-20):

# Auditoría Completa de Asignación de Pines - CDPR

Este documento presenta una auditoría completa del hardware y la configuración de pines definida en el firmware del CDPR (Robot Paralelo Accionado por Cables) para verificar posibles colisiones y proponer una solución viable que prescinda del expansor de pines **MCP23017**, utilizando únicamente los recursos nativos de los dos **ESP32** (Maestro y Esclavo).

---

## 1. Estado Actual del Firmware y Verificación de Conflictos

### ESP32 MAIN (Maestro) - Configuración Actual
Actualmente, el ESP32 MAIN controla la generación de PWM para los 8 motores, gestiona la comunicación UART con el esclavo, se comunica por I2C con el expansor MCP23017 y controla la línea de habilitación `STBY`.

| Función | Pin GPIO | Estado / Observación | ¿Conflicto? |
| :--- | :--- | :--- | :--- |
| **UART0 TX** | GPIO 1 | Usado para depuración y carga de firmware (USB Serial). | **No** (Esperado) |
| **UART0 RX** | GPIO 3 | Usado para depuración y carga de firmware (USB Serial). | **No** (Esperado) |
| **UART2 RX** | GPIO 16 | Interconexión con ESP32 ENCODER. | **No** |
| **UART2 TX** | GPIO 17 | Interconexión con ESP32 ENCODER. | **No** |
| **I2C SDA** | GPIO 21 | Comunicación con el expansor MCP23017. | **No** |
| **I2C SCL** | GPIO 22 | Comunicación con el expansor MCP23017. | **No** |
| **STBY (Unificado)**| GPIO 5 | Desactivación física global de los drivers TB6612FNG. | **No** |
| **Motor 0 PWM** | GPIO 2 | Pin de PWM del Motor 0. (Strapping pin: LED integrado). | **No** |
| **Motor 1 PWM** | GPIO 12 | Pin de PWM del Motor 1. (Strapping pin: MTDI). | **No** |
| **Motor 2 PWM** | GPIO 14 | Pin de PWM del Motor 2. | **No** |
| **Motor 3 PWM** | GPIO 23 | Pin de PWM del Motor 3. | **No** |
| **Motor 4 PWM** | GPIO 27 | Pin de PWM del Motor 4. | **No** |
| **Motor 5 PWM** | GPIO 18 | Pin de PWM del Motor 5. | **No** |
| **Motor 6 PWM** | GPIO 19 | Pin de PWM del Motor 6. | **No** |
| **Motor 7 PWM** | GPIO 25 | Pin de PWM del Motor 7. | **No** |

> [!WARNING]
> **Pines de Arranque (Strapping Pins) en el Maestro:**
> - **GPIO 12 (MTDI):** Si durante el encendido este pin es forzado a nivel HIGH por el circuito externo, el voltaje de la memoria flash interna del ESP32 se configurará a 1.8V en lugar de 3.3V, impidiendo que el microcontrolador arranque. Se debe garantizar que la impedancia de entrada del pin PWM del puente H no lo mantenga en alto durante el reset.
> - **GPIO 2:** Debe permanecer en nivel LOW o flotante durante el inicio para entrar en modo de ejecución normal.

---

### ESP32 ENCODER (Esclavo) - Configuración Actual
El ESP32 ENCODER lee los 8 encoders ópticos de cuadratura (16 señales) usando los contadores de hardware (PCNT) y transmite la posición acumulada vía UART2.

| Motor | Canal A | Canal B | Unidad PCNT | ¿Conflicto Interno? |
| :--- | :--- | :--- | :--- | :--- |
| **Motor 0** | GPIO 34 | GPIO 35 | PCNT 0 | **No** (Pines Input-only nativos, excelente) |
| **Motor 1** | GPIO 36 | GPIO 39 | PCNT 1 | **No** (Pines Input-only nativos, excelente) |
| **Motor 2** | GPIO 32 | GPIO 33 | PCNT 2 | **No** |
| **Motor 3** | GPIO 25 | GPIO 26 | PCNT 3 | **No** |
| **Motor 4** | GPIO 27 | GPIO 13 | PCNT 4 | **No** |
| **Motor 5** | GPIO 23 | GPIO 19 | PCNT 5 | **No** |
| **Motor 6** | GPIO 4 | GPIO 15 | PCNT 6 | **No** (GPIO 15 es strapping pin) |
| **Motor 7** | GPIO 18 | GPIO 14 | PCNT 7 | **No** |
| **UART2 RX** | GPIO 16 | - | Interconexión UART. | **No** |
| **UART2 TX** | GPIO 17 | - | Interconexión UART. | **No** |

> [!WARNING]
> **Pines de Arranque (Strapping Pins) en el Esclavo:**
> - **GPIO 15 (MTDO):** Controla la salida de logs de arranque. Si se conecta a un encoder, los pulsos durante el arranque no causarán fallos críticos, pero es buena práctica no colocar resistencias pull-down fuertes en esta línea.

---

## 2. Auditoría del Límite de Pines y el Expansor MCP23017

El diseño actual **SÍ utiliza un expansor de pines (MCP23017)** para controlar las señales de dirección `IN1` e `IN2` de los 8 motores (16 señales digitales de salida en total).

### ¿Por qué se colocó el expansor MCP23017 en el diseño inicial?
Para controlar 8 motores de manera centralizada desde un único ESP32 Maestro sin usar expansores, necesitaríamos:
- 8 señales PWM (salidas)
- 16 señales de dirección IN1/IN2 (salidas)
- 1 señal STBY (salida)
- 2 señales de comunicación UART2 (TX/RX)
- **Total = 27 pines de salida/entrada digitales.**

El ESP32 de 38 pines estándar solo tiene **21 pines GPIO configurables como salida**. Los pines 34, 35, 36 y 39 son únicamente de entrada. Los pines 6 al 11 están conectados a la memoria flash integrada y no se pueden usar. Por lo tanto, **físicamente es imposible controlar los 8 motores (PWM + Direcciones completas) y la UART usando un solo ESP32 sin expansores.**

---

## 3. Propuesta de Arquitectura Alternativa: Distribución Simétrica (Sin Expansores)

Para cumplir estrictamente con el requerimiento de **no utilizar expansores de pines** y usar solo los recursos nativos de los dos ESP32, se debe rediseñar la arquitectura lógica y física del robot:

### Solución: Reparto Simétrico de Motores (4 Motores por ESP32)
En lugar de especializar un ESP32 en control de motores y otro en encoders, **distribuimos los 8 motores de manera uniforme**:
1. **ESP32 Maestro (MAIN):** Controla directamente los **Motores 0, 1, 2 y 3** (PWM, Direcciones y Lectura de Encoders locales).
2. **ESP32 Auxiliar (SUB):** Controla directamente los **Motores 4, 5, 6 y 7** (PWM, Direcciones y Lectura de Encoders locales).

Ambos ESP32 intercambian comandos de sincronización a través de la UART2 a 1 kHz. El Maestro calcula la cinemática de los 8 cables, aplica el PID para sus 4 motores locales y envía los comandos de posición/velocidad al ESP32 Auxiliar para sus 4 motores, recibiendo de vuelta el estado de los mismos.

### Viabilidad de Pines por ESP32 en Distribución Simétrica
Para controlar y leer **4 motores** en una sola placa ESP32, se requiere:
- Encoders: 4 motores × 2 canales = 8 entradas (4 de ellas pueden usar los pines input-only 34, 35, 36, 39).
- PWM: 4 salidas.
- Direcciones (IN1, IN2): 8 salidas.
- Standby (STBY): 1 salida unificada.
- UART2: 2 pines (TX/RX).
- **Total de Pines de Salida/Comunicación necesarios = 4 (PWM) + 8 (DIR) + 1 (STBY) + 2 (UART) = 15 pines de propósito general.**
- **Total de Pines de Entrada necesarios = 4 pines de entrada general (o input-only).**

Esto encaja perfectamente dentro de los límites físicos de un ESP32 estándar (21 GPIOs bidireccionales + 4 GPIOs input-only).

---

## 4. Tabla de Asignación de Pines Propuesta (Sin Expansores)

A continuación se muestra el mapa de pines óptimo y libre de conflictos para implementar esta arquitectura distribuida sin expansores de pines.

### Placa 1: ESP32 Maestro (MAIN) - Motores 0 a 3
| Dispositivo / Función | Señal | Pin GPIO | Tipo | Notas / Strapping |
| :--- | :--- | :--- | :--- | :--- |
| **Interconexión UART** | UART2 RX2 | **GPIO 16** | Input | Interconexión con Placa 2 |
| **Interconexión UART** | UART2 TX2 | **GPIO 17** | Output | Interconexión con Placa 2 |
| **Seguridad Driver** | STBY | **GPIO 5** | Output | Habilitación global motores 0-3. Strapping normal. |
| **Motor 0** | PWM | **GPIO 2** | Output | Strapping (mantener flotante/bajo en boot) |
| **Motor 0** | IN1 | **GPIO 4** | Output | Dirección 1 |
| **Motor 0** | IN2 | **GPIO 15** | Output | Dirección 2. Strapping. |
| **Motor 0** | Enc A | **GPIO 34** | Input | Input-only |
| **Motor 0** | Enc B | **GPIO 35** | Input | Input-only |
| **Motor 1** | PWM | **GPIO 12** | Output | Strapping (MTDI: evitar pull-up fuerte) |
| **Motor 1** | IN1 | **GPIO 13** | Output | Dirección 1 |
| **Motor 1** | IN2 | **GPIO 14** | Output | Dirección 2 |
| **Motor 1** | Enc A | **GPIO 36** | Input | Input-only |
| **Motor 1** | Enc B | **GPIO 39** | Input | Input-only |
| **Motor 2** | PWM | **GPIO 25** | Output | Control PWM |
| **Motor 2** | IN1 | **GPIO 26** | Output | Dirección 1 |
| **Motor 2** | IN2 | **GPIO 27** | Output | Dirección 2 |
| **Motor 2** | Enc A | **GPIO 32** | Input | Entrada Encoder (Soporta ADC/Touch) |
| **Motor 2** | Enc B | **GPIO 33** | Input | Entrada Encoder (Soporta ADC/Touch) |
| **Motor 3** | PWM | **GPIO 18** | Output | Control PWM |
| **Motor 3** | IN1 | **GPIO 19** | Output | Dirección 1 |
| **Motor 3** | IN2 | **GPIO 23** | Output | Dirección 2 |
| **Motor 3** | Enc A | **GPIO 21** | Input | Entrada Encoder (SDA si se requiere I2C) |
| **Motor 3** | Enc B | **GPIO 22** | Input | Entrada Encoder (SCL si se requiere I2C) |

---

### Placa 2: ESP32 Auxiliar (SUB/ENCODER) - Motores 4 a 7
| Dispositivo / Función | Señal | Pin GPIO | Tipo | Notas / Strapping |
| :--- | :--- | :--- | :--- | :--- |
| **Interconexión UART** | UART2 RX2 | **GPIO 16** | Input | Conexión cruzada a TX2 de Placa 1 |
| **Interconexión UART** | UART2 TX2 | **GPIO 17** | Output | Conexión cruzada a RX2 de Placa 1 |
| **Seguridad Driver** | STBY | **GPIO 5** | Output | Habilitación global motores 4-7. |
| **Motor 4** | PWM | **GPIO 2** | Output | Strapping (mantener flotante/bajo en boot) |
| **Motor 4** | IN1 | **GPIO 4** | Output | Dirección 1 |
| **Motor 4** | IN2 | **GPIO 15** | Output | Dirección 2. Strapping. |
| **Motor 4** | Enc A | **GPIO 34** | Input | Input-only |
| **Motor 4** | Enc B | **GPIO 35** | Input | Input-only |
| **Motor 5** | PWM | **GPIO 12** | Output | Strapping (MTDI: evitar pull-up fuerte) |
| **Motor 5** | IN1 | **GPIO 13** | Output | Dirección 1 |
| **Motor 5** | IN2 | **GPIO 14** | Output | Dirección 2 |
| **Motor 5** | Enc A | **GPIO 36** | Input | Input-only |
| **Motor 5** | Enc B | **GPIO 39** | Input | Input-only |
| **Motor 6** | PWM | **GPIO 25** | Output | Control PWM |
| **Motor 6** | IN1 | **GPIO 26** | Output | Dirección 1 |
| **Motor 6** | IN2 | **GPIO 27** | Output | Dirección 2 |
| **Motor 6** | Enc A | **GPIO 32** | Input | Entrada Encoder |
| **Motor 6** | Enc B | **GPIO 33** | Input | Entrada Encoder |
| **Motor 7** | PWM | **GPIO 18** | Output | Control PWM |
| **Motor 7** | IN1 | **GPIO 19** | Output | Dirección 1 |
| **Motor 7** | IN2 | **GPIO 23** | Output | Dirección 2 |
| **Motor 7** | Enc A | **GPIO 21** | Input | Entrada Encoder |
| **Motor 7** | Enc B | **GPIO 22** | Input | Entrada Encoder |

---

## 5. Conclusiones y Recomendaciones de la Auditoría

1. **Estado Actual:** No existen colisiones de pines en la configuración cargada actualmente, pero **sí se está usando un expansor de pines MCP23017** por hardware e I2C en el maestro para controlar las direcciones de los motores.
2. **Uso de Extensor:** Para poder eliminar el MCP23017 y cumplir con el requerimiento de usar únicamente los dos ESP32, es **mandatorio abandonar el esquema Maestro-Motor / Esclavo-Encoder puro** y adoptar el **Esquema de Distribución Simétrica (4 motores por placa)** detallado en la sección 4.
3. **Pines Críticos:** Se debe prestar especial atención a los pines de arranque **GPIO 12, 15 y 2** en ambas placas al realizar el cableado físico para evitar problemas de booteo o de flasheo.

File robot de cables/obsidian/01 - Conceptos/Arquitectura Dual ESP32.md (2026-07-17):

---
tags: [proyecto/cdpr, tipo/concepto]
estado: validado
creado: 2026-07-16
---
relacionado: [[00 - MOC CDPR]], [[Protocolo UART Binario]], [[Esquema de Conexiones y Pines]], [[Decisiones de Diseño]]
---

# Arquitectura Dual ESP32

## Definición
La arquitectura dual ESP32 distribuye la carga del sistema de control del robot paralelo accionado por cables (CDPR) en dos microcontroladores interconectados a través de un bus UART binario a alta velocidad (921600 bps).

---

## Conceptos Clave
- **ESP32 MAIN (Maestro)**:
  - Ejecuta la cinemática inversa y la planificación de trayectorias.
  - Gestiona el bucle de control PID a 1 kHz.
  - Proporciona conectividad WiFi, WebSocket y servidor web para la interfaz de control.
  - Controla la dirección física de los motores mediante el expansor de E/S MCP23017 por I2C.
- **ESP32 ENCODER (Esclavo)**:
  - Lee los encoders incrementales de los 8 motores en paralelo.
  - Utiliza las unidades periféricas de hardware **PCNT (Pulse Counter)** integradas en el ESP32 para contar los pulsos de cuadratura sin interrumpir la CPU.
  - Transmite periódicamente los conteos acumulados (ticks) al Maestro por UART a 1 kHz.

---

## Medidas de Seguridad del Sistema
1. **Protección de Enlace (Timeout UART)**: Si el Maestro no recibe telemetría del Esclavo durante más de 50 ms, transiciona inmediatamente a `STATE_ESTOP` (Parada de Emergencia) y apaga los controladores por hardware.
2. **Protección contra Reinicios (BOOT_ID)**: El Esclavo genera un identificador aleatorio (`BOOT_ID`) en el arranque. Si este identificador cambia, el Maestro detecta que el Esclavo se ha reiniciado (perdiendo su posición de referencia) y fuerza un `STATE_ESTOP`.
3. **Resincronización de Tramas**: Si se detecta un byte corrupto, el parseador se restablece tras 5 ms de inactividad para evitar bloqueos del lazo de control.

---

## Ejemplos de Flujo de Operación
```mermaid
sequenceDiagram
    participant Maestro as ESP32 MAIN
    participant Esclavo as ESP32 ENCODER
    loop Bucle de Control a 1 kHz
        Esclavo->>Maestro: Ticks de Encoders (Frame Telemetría, 38 bytes)
        Note over Maestro: Calcula la pose actual y error PID
        Note over Maestro: Cinemática inversa para setpoints
        Note over Maestro: Genera comandos PWM
        Maestro->>Esclavo: Comandos de PWM en Simulación (Frame PWM, 37 bytes)
    end
```

---

## Enlaces Relacionados
- [[00 - MOC CDPR]]
- [[Robot Paralelo de Cables 6-DOF]]
- [[Protocolo UART Binario]]
- [[Esquema de Conexiones y Pines]]
- [[Decisiones de Diseño]]

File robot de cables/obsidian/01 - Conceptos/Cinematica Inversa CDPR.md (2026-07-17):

---
tags: [proyecto/cdpr, tipo/concepto]
estado: validado
creado: 2026-07-16
---
relacionado: [[00 - MOC CDPR]], [[Control PID de Posicion]], [[Simulador Python CDPR]], [[Plan de Pruebas de Cinemática]]
---

# Cinemática Inversa CDPR

## Definición
La cinemática inversa determina la longitud requerida para cada uno de los 8 cables del Robot Paralelo Accionado por Cables (CDPR) a partir de una pose deseada de la plataforma móvil definida en 6 grados de libertad ($X, Y, Z, Roll, Pitch, Yaw$).

---

## Modelo Matemático y Geométrico

Dada la pose del efector final definida por su traslación $\mathbf{p} = [x, y, z]^T$ y su orientación en ángulos de Euler de Tait-Bryan $\boldsymbol{\theta} = [\phi, \theta, \psi]^T$ (Roll, Pitch, Yaw):

1. **Matriz de Rotación $\mathbf{R}$ ($R_{zyx}$)**:
   $$
   \mathbf{R} = \mathbf{R}_z(\psi) \mathbf{R}_y(\theta) \mathbf{R}_x(\phi)
   $$
   
2. **Posición de los Anclajes en el Espacio del Mundo ($\mathbf{q}_i$)**:
   Si $\mathbf{a}_i$ es la posición local del punto de anclaje del cable $i$ en la plataforma móvil:
   $$
   \mathbf{q}_i = \mathbf{p} + \mathbf{R} \mathbf{a}_i \quad \text{para } i = 0, \dots, 7
   $$

3. **Cálculo de la Longitud del Cable ($L_i$)**:
   Si $\mathbf{b}_i$ representa la posición de la polea fija de salida en el poste del marco estructural del robot:
   $$
   L_i = \|\mathbf{b}_i - \mathbf{q}_i\|_2 = \sqrt{(b_{ix} - q_{ix})^2 + (b_{iy} - q_{iy})^2 + (b_{iz} - q_{iz})^2}
   $$

---

## Geometría del Robot (Configuración Física en cm)

### Coordenadas de las Poleas Fijadas al Marco ($\mathbf{b}_i$)
```text
POLE_POSITIONS = [
    [-22.5, -21.0, 45.0], // Cable 0
    [-21.0, -22.5, 45.0], // Cable 1
    [ 21.0, -22.5, 45.0], // Cable 2
    [ 22.5, -21.0, 45.0], // Cable 3
    [ 22.5,  21.0, 45.0], // Cable 4
    [ 21.0,  22.5, 45.0], // Cable 5
    [-21.0,  22.5, 45.0], // Cable 6
    [-22.5,  21.0, 45.0]  // Cable 7
]
```

### Coordenadas de los Anclajes en la Plataforma Móvil ($\mathbf{a}_i$)
```text
ANCHOR_POSITIONS = [
    [-5.0, -4.0, 0.0], // Cable 0
    [-4.0, -5.0, 0.0], // Cable 1
    [ 4.0, -5.0, 0.0], // Cable 2
    [ 5.0, -4.0, 0.0], // Cable 3
    [ 5.0,  4.0, 0.0], // Cable 4
    [ 4.0,  5.0, 0.0], // Cable 5
    [-4.0,  5.0, 0.0], // Cable 6
    [-5.0,  4.0, 0.0]  // Cable 7
]
```

---

## Implementación en Python
La función calcula la longitud teórica de cada cable de la siguiente manera:
```python
def calculate_inverse_kinematics(x, y, z, roll, pitch, yaw):
    cr, sr = math.cos(roll), math.sin(roll)
    cp, sp = math.cos(pitch), math.sin(pitch)
    cy, sy = math.cos(yaw), math.sin(yaw)

    # Coeficientes de la matriz de rotación R
    r11, r12, r13 = cy*cp, cy*sp*sr - sy*cr, cy*sp*cr + sy*sr
    r21, r22, r23 = sy*cp, sy*sp*sr + cy*cr, sy*sp*cr - cy*sr
    r31, r32, r33 = -sp,   cp*sr,            cp*cr

    lengths = []
    for i in range(8):
        ax, ay, az = ANCHOR_POSITIONS[i]
        qx = x + (r11 * ax + r12 * ay + r13 * az)
        qy = y + (r21 * ax + r22 * ay + r23 * az)
        qz = z + (r31 * ax + r32 * ay + r33 * az)

        dx = POLE_POSITIONS[i][0] - qx
        dy = POLE_POSITIONS[i][1] - qy
        dz = POLE_POSITIONS[i][2] - qz
        lengths.append(math.sqrt(dx**2 + dy**2 + dz**2))
    return lengths
```

---

## Enlaces Relacionados
- [[00 - MOC CDPR]]
- [[Robot Paralelo de Cables 6-DOF]]
- [[Control PID de Posicion]]
- [[Simulador Python CDPR]]
- [[Plan de Pruebas de Cinemática]]

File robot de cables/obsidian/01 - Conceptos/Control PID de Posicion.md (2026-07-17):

---
tags: [proyecto/cdpr, tipo/concepto]
estado: validado
creado: 2026-07-16
---
relacionado: [[00 - MOC CDPR]], [[Cinematica Inversa CDPR]], [[Esquema de Conexiones y Pines]], [[Decisiones de Diseño]]
---

# Control PID de Posición

## Definición
Algoritmo de control realimentado que calcula de manera continua la señal PWM de control aplicada a cada uno de los 8 motores DC reductores basándose en el error de posición en ticks de encoder.

---

## Formulación del Controlador

Para cada motor, la salida de control $u(t)$ en el instante $t$ se define como:
$$
u(t) = K_p \, e(t) + K_i \int_{0}^{t} e(\tau) d\tau + K_d \, \frac{de(t)}{dt}
$$
Donde el error de posición $e(t)$ es:
$$
e(t) = \text{target\_ticks} - \text{current\_ticks}
$$

### Constantes de Sintonización
- **$K_p$ (Proporcional)** = $8.5$
- **$K_i$ (Integral)** = $0.1$
- **$K_d$ (Derivativo)** = $0.4$

---

## Características de Diseño Especiales

1. **Anti-Windup**: 
   La acumulación del término integral se restringe a un límite estricto utilizando la función `constrain` en el rango de $[-50.0, 50.0]$ para prevenir saturación prolongada.
   
   > [!WARNING]
   > **Análisis de Límites de Integral**:
   > Con un límite de integral de $\pm 50.0$ y un coeficiente $K_i = 0.1$, la contribución máxima del término integral a la salida de control PWM es de apenas $\pm 5.0$ (sobre un rango de $\pm 255$). En presencia de cargas gravitatorias constantes u oposición friccional alta, esta saturación podría ser demasiado baja, induciendo un error persistente en estado estacionario.
   
2. **Torque de Retención Activo (Anti-Holgura)**:
   Puesto que los cables no pueden empujar (sólo jalar), se requiere mantener una tensión constante mínima en todo momento.
   - Si la señal calculada por el PID $u(t) > 0$ pero es menor que `HOLDING_TORQUE_PWM` ($25$), se fuerza a $25$.
   - Si la plataforma está muy cerca del objetivo (error $< 50$ ticks, aprox $1.5\text{ mm}$), se aplica una consigna de retención de $25$ PWM para mantener el cable tenso y evitar la flacidez del cable.
3. **Freno Activo (Short-Brake)**:
   Cuando la consigna $u(t)$ es exactamente $0$, los pines del expansor MCP23017 se configuran a `IN1 = LOW, IN2 = LOW` provocando el cortocircuito del puente H de los TB6612FNG para bloquear dinámicamente el motor.

---

## Conversión Ticks a Centímetros
El sistema utiliza las siguientes constantes físicas para convertir de distancias espaciales (cinemática) a ticks de encoder:
- Relación de Reducción: $45:1$
- Pulsos Por Revolución (PPR) de Encoder: $11.0$ (Cuadratura: $\times 4$)
- Radio del Tambor de Cable: $1.0\text{ cm}$
- Ticks por Revolución: $11 \times 4 \times 45 = 1980\text{ ticks}$
- **Factor de Conversión (`TICKS_PER_CM`)**:
  $$
  \text{TICKS\_PER\_CM} = \frac{1980}{2 \pi \cdot 1.0} \approx 315.127 \text{ ticks/cm}
  $$

---

## Enlaces Relacionados
- [[00 - MOC CDPR]]
- [[Robot Paralelo de Cables 6-DOF]]
- [[Cinematica Inversa CDPR]]
- [[Esquema de Conexiones y Pines]]
- [[Decisiones de Diseño]]

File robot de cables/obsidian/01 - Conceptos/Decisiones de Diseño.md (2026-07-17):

---
tags: [proyecto/cdpr, tipo/concepto]
estado: validado
creado: 2026-07-16
---
relacionado: [[00 - MOC CDPR]], [[Arquitectura Dual ESP32]], [[Esquema de Conexiones y Pines]]
---

# Decisiones de Diseño

En este documento se registran y justifican técnicamente las decisiones de diseño tomadas para la arquitectura y el hardware del Robot Paralelo Accionado por Cables (CDPR) de 6-DOF.

---

## ⚖️ Análisis de Decisiones Clave

### 1. ¿Por qué 8 cables para 6 grados de libertad?
- **Problema**: Los cables son elementos unidireccionales (solo pueden ejercer fuerza en tensión, no en compresión).
- **Decisión**: Se optó por una configuración **redundante en cables** de $m = 8$ cables para un sistema de $n = 6$ grados de libertad ($m = n + 2$).
- **Justificación**:
  - En un robot de cables con la misma cantidad de cables que de grados de libertad ($m = n = 6$), es imposible mantener la tensión en todos los cables en todo el espacio de trabajo. Habrá direcciones en las que el robot se volverá inestable o perderá rigidez.
  - Al añadir redundancia ($8$ cables), siempre es posible encontrar una distribución de tensiones estrictamente positiva (todos los cables tensos) para cualquier pose dentro del espacio de trabajo estático útil, eliminando singularidades internas y mejorando la rigidez dinámica.

### 2. ¿Por qué una Arquitectura Dual ESP32 en lugar de un único ESP32?
- **Problema**: La lectura de 8 encoders incrementales con canales A/B en cuadratura requiere 16 pines rápidos y la gestión de 8 periféricos PCNT. Al mismo tiempo, el control PID de 8 motores requiere 8 canales PWM, 16 señales de dirección de puente H (por I2C), el cálculo de la cinemática inversa flotante, y la gestión del servidor Web/WebSockets por WiFi a 1 kHz.
- **Decisión**: Separar el sistema en un **ESP32 MAIN (Maestro)** y un **ESP32 ENCODER (Esclavo)**.
- **Justificación**:
  - **Contención de Pines**: El ESP32 no cuenta con suficientes GPIOs accesibles simultáneamente sin interferir con las memorias flash internas (pines de strapping y SDIO) y la conectividad WiFi.
  - **Latencia de Interrupciones y Context Switching**: La tarea de lectura y acumulación de encoders por software afectaría la constancia del lazo PID a 1 kHz. Delegar los contadores PCNT de hardware a una placa secundaria libera al Maestro para realizar operaciones cinemáticas complejas en punto flotante sin jitter.

### 3. ¿Por qué usar el expansor MCP23017 en vez de GPIOs directos para la dirección?
- **Problema**: Controlar la dirección de 8 motores mediante puentes H convencionales requiere 2 pines discretos por motor ($16$ pines en total).
- **Decisión**: Utilizar un expansor de puertos GPIO de 16 bits **MCP23017** controlado por I2C a alta velocidad ($400\text{ kHz}$).
- **Justificación**:
  - Al utilizar I2C, solo se consumen 2 pines del ESP32 MAIN (SDA/SCL) en lugar de 16 pines discretos.
  - Las señales de dirección (`IN1`/`IN2`) de los TB6612FNG no requieren conmutación rápida de microsegundos (a diferencia del PWM), por lo que la velocidad del bus I2C a 400 kHz es más que suficiente para actualizarlas dentro del ciclo de control de 1 ms (1 kHz).

---

## Enlaces Relacionados
- [[00 - MOC CDPR]]
- [[Robot Paralelo de Cables 6-DOF]]
- [[Arquitectura Dual ESP32]]
- [[Control PID de Posicion]]

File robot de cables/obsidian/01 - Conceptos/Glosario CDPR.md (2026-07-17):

---
tags: [proyecto/cdpr, tipo/concepto]
estado: validado
creado: 2026-07-16
relacionado: [[00 - MOC CDPR]]
---

# Glosario CDPR

Diccionario de términos técnicos y conceptos utilizados en el diseño, desarrollo y control de nuestro Robot Paralelo Accionado por Cables (CDPR).

---

## 📖 Definición de Términos

- **CDPR (Cable-Driven Parallel Robot)**: Robot paralelo en el cual la plataforma móvil (efector final) está suspendida y controlada mediante la tracción coordinada de múltiples cables flexibles.
- **PCNT (Pulse Counter)**: Periférico de hardware del ESP32 diseñado para contar transiciones de señal (flancos de subida y bajada) en canales de entrada de manera autónoma, consumiendo cero ciclos de CPU. Es clave para decodificar los canales de cuadratura de los encoders incrementales de los motores.
- **Anti-Windup**: Lógica de protección en controladores PID que detiene o limita la acumulación del término integral cuando la señal de salida calculada satura los límites físicos del actuador (en nuestro caso, $\pm 255$ PWM), previniendo sobreoscilaciones prolongadas al cambiar de dirección.
- **Torque de Retención Activo (Anti-Holgura)**: Valor mínimo de tensión (expresado en ciclo de trabajo PWM, en nuestro caso $25$) que se aplica a los motores de los cables que no están experimentando fuerzas de tracción principales para evitar que queden flácidos (holgura).
- **Freno Activo (Short-Brake)**: Método de frenado en puentes H (como el TB6612FNG) que cortocircuita los dos terminales del motor a tierra (`IN1 = LOW, IN2 = LOW`). Esto aprovecha la fuerza contraelectromotriz del motor DC para detener la inercia del tambor de forma inmediata.
- **CRC-8 (Cyclic Redundancy Check de 8 bits)**: Algoritmo de detección de errores de transmisión utilizado para validar la integridad de las tramas UART binarias compartidas a 1 kHz entre el ESP32 MAIN y el ESP32 ENCODER. Se utiliza el polinomio Dallas/Maxim ($0x31$).
- **Strapping Pins (Pines de Configuración)**: Pines del ESP32 (como GPIO 12, GPIO 2, GPIO 15, GPIO 0, GPIO 5) que son leídos por la ROM interna del microcontrolador al arrancar (boot) para configurar el modo de ejecución, voltaje de flash o el comportamiento de la señal de reloj. Su uso inadecuado puede impedir el encendido del microcontrolador.
- **Matriz de Rotación $R_{zyx}$**: Matriz matemática ortogonal en 3D que describe la orientación espacial del efector final mediante la secuencia de rotaciones de Tait-Bryan en los ejes Z (Yaw), Y (Pitch) e X (Roll).
- **Workspace (Espacio de Trabajo)**: El volumen en el espacio 3D que puede alcanzar físicamente el efector final del robot manteniendo todos los cables bajo una tensión mínima aceptable.

---

## Enlaces Relacionados
- [[00 - MOC CDPR]]
- [[Robot Paralelo de Cables 6-DOF]]
- [[Cinematica Inversa CDPR]]
- [[Control PID de Posicion]]

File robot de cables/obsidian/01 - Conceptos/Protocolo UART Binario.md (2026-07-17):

---
tags: [proyecto/cdpr, tipo/concepto]
estado: validado
creado: 2026-07-16
---
relacionado: [[00 - MOC CDPR]], [[Arquitectura Dual ESP32]], [[Esquema de Conexiones y Pines]]
---

# Protocolo UART Binario

## Definición
Es el protocolo de comunicación serie punto a punto a 921600 bps que conecta el ESP32 MAIN y el ESP32 ENCODER de manera compacta y de baja latencia para garantizar el control en tiempo real a 1 kHz.

---

## Estructura de las Tramas

### 1. Trama de Telemetría (ENCODER $\rightarrow$ MAIN)
Tiene una longitud fija de **38 bytes** y se transmite de forma síncrona a 1 kHz.
- **SOF 1 & 2** (2 bytes): `0xAA 0xBB` (Start of Frame)
- **LENGTH** (1 byte): `0x20` (32 bytes de payload)
- **SEQ** (1 byte): Contador circular de secuencia (0-255)
- **BOOT_ID** (1 byte): Identificador único de arranque generado aleatoriamente.
- **PAYLOAD** (32 bytes): `int32_t encoder_ticks[8]` (Ticks acumulados de encoders de los 8 motores).
- **CRC8** (1 byte): Código de redundancia cíclica calculado sobre los bytes 3 a 36 utilizando el polinomio **Dallas/Maxim (0x31)** ($x^8 + x^5 + x^4 + 1$).

### 2. Trama de Simulación PWM (MAIN $\rightarrow$ ENCODER)
Se utiliza únicamente en `SIMULATION_MODE=1` para transmitir las consignas del lazo PID del Maestro hacia el simulador dinámico del Esclavo. Su longitud es de **37 bytes**.
- **SOF 1 & 2** (2 bytes): `0xCC 0xDD`
- **LENGTH** (1 byte): `0x20` (32 bytes de payload)
- **SEQ** (1 byte): Contador de secuencia circular.
- **PAYLOAD** (32 bytes): `float motor_pwm[8]` (Consignas PWM en rango $[-255.0, 255.0]$).
- **CRC8** (1 byte): Dallas/Maxim CRC-8 calculado sobre los bytes 3 a 35.

---

## Algoritmo CRC-8 (Implementación en C++)
```cpp
uint8_t calculateCRC8(const uint8_t *data, size_t len) {
    uint8_t crc = 0x00;
    for (size_t i = 0; i < len; i++) {
        crc ^= data[i];
        for (uint8_t j = 0; j < 8; j++) {
            if (crc & 0x80) {
                crc = (crc << 1) ^ 0x31; // Polinomio Dallas/Maxim
            } else {
                crc <<= 1;
            }
        }
    }
    return crc;
}
```

---

## Enlaces Relacionados
- [[00 - MOC CDPR]]
- [[Robot Paralelo de Cables 6-DOF]]
- [[Arquitectura Dual ESP32]]
- [[Esquema de Conexiones y Pines]]

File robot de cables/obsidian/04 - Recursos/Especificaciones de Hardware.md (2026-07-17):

---
tags: [proyecto/cdpr, tipo/recurso]
estado: borrador
creado: 2026-07-16
---
relacionado: [[00 - MOC CDPR]], [[Esquema de Conexiones y Pines]]
---

# Especificaciones de Hardware

Ficha técnica y características consolidadas del hardware utilizado para la construcción e integración del Robot Paralelo Accionado por Cables (CDPR).

---

## ⚡ Especificación Eléctrica y Electrónica

### 1. Controladores Principales
- **ESP32 MAIN (Maestro)**: Microcontrolador Tensilica dual-core a 240 MHz con conectividad WiFi/Bluetooth. Encargado de cinemática inversa, lazo PID a 1 kHz y servidor web interactivo.
- **ESP32 ENCODER (Esclavo)**: Microcontrolador secundario dedicado. Utiliza las 8 unidades de contadores de pulsos físicos por hardware (**PCNT**) para decodificar encoders en cuadratura sin sobrecargar el procesador.

### 2. Controladores de Motores (Puentes H)
- **Chips**: 4x Módulos Breakout **TB6612FNG**.
- **Canales**: 2 puentes H por circuito integrado, permitiendo controlar un total de 8 motores DC.
- **Corriente Nominal**: $1.2\text{ A}$ continuos por canal ($3.2\text{ A}$ de pico).
- **Control**: Señales PWM conectadas a GPIOs dedicados del ESP32 MAIN y señales de dirección (`IN1`/`IN2`) controladas por el expansor de E/S MCP23017.
- **Línea STBY**: Todos los pines de standby de los drivers están unificados físicamente y conectados al GPIO 5 del ESP32 MAIN para permitir un apagado por hardware instantáneo.

### 3. Expansor de Puertos I2C
- **Chip**: **MCP23017** de 16 bits.
- **Dirección I2C**: $0x20$ (Configurable por hardware mediante pines A0, A1, A2).
- **Frecuencia de Operación**: Modo rápido de I2C ($400\text{ kHz}$).

---

## ⚙️ Especificación Mecánica y Actuadores

### 1. Motores y Encoders
- **Tipo de Motor**: Motor DC reductor (modelo específico pendiente de confirmación, ej. *Pololu 25D mm*).
- **Voltaje de Alimentación**: $12\text{ V}$ nominales (máximo del TB6612FNG: $15\text{ V}$).
- **Relación de Reducción (`GEAR_RATIO`)**: $45:1$.
- **Encoder**: Incremental de cuadratura (2 canales A/B) acoplado al eje del motor antes de la reducción.
- **Resolución (`ENCODER_PPR`)**: $11.0$ pulsos por revolución del eje del motor (PPR).
- **Tambor de Bobinado**: Tambor cilíndrico de radio $r = 1.0\text{ cm}$ acoplado al eje de salida.

### 2. Estructura Física y Cables
- **Estructura del Robot**: Marco cuadrangular de postes verticales.
  - Dimensiones del volumen de trabajo útil aproximado: $45\text{ cm} \times 45\text{ cm} \times 45\text{ cm}$ (según coordenadas de poleas).
- **Cables**: Hilo de pescar trenzado de polietileno de ultra alto peso molecular (Dyneema/Spectra) o hilo de nylon de alta resistencia a la tracción.
- **Poleas**: Poleas fijas con rodamientos situadas en las 4 esquinas superiores de la estructura.

---

> [!WARNING]
> **Datos Pendientes por Validar en Campo**:
> 1. **Modelo exacto de los motores**: Confirmar la corriente máxima en rotor bloqueado (stall current) para evitar sobrepasar el límite de los TB6612FNG ($1.2\text{ A}$ continuo).
> 2. **Tensión del cable máxima recomendada**: Límite de carga de rotura del cable utilizado.
> 3. **Fuente de poder**: Capacidad en Amperios de la fuente de 12V necesaria para alimentar los 8 motores simultáneamente en condiciones de alta carga.

---

## Enlaces Relacionados
- [[00 - MOC CDPR]]
- [[Esquema de Conexiones y Pines]]
- [[Robot Paralelo de Cables 6-DOF]]

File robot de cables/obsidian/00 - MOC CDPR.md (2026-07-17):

---
tags: [proyecto/cdpr, tipo/moc]
estado: validado
creado: 2026-07-16
relacionado: []
---

# 🗺️ MOC - Robot Paralelo de Cables 6-DOF (CDPR)

Bienvenido al panel central de navegación de tu segundo cerebro para el **Robot Paralelo Accionado por Cables (CDPR)**. Este mapa de contenido organiza los archivos de la bóveda para facilitar la consulta y es totalmente compatible con consultas de Dataview.

---

## 📌 Gestión de Proyecto
- [[Robot Paralelo de Cables 6-DOF]] — Nota principal del proyecto y resumen.
- [[Roadmap del Proyecto]] — Hitos del proyecto, objetivos y estado de tareas.
- [[Bitácora de Pruebas]] — Registro cronológico de experimentos y resultados.

## 🧠 Conceptos y Teoría
- [[Decisiones de Diseño]] — Justificación de hardware, la arquitectura dual y cantidad de cables.
- [[Cinematica Inversa CDPR]] — Ecuaciones geométricas y transformaciones de pose a longitudes de cable.
- [[Control PID de Posicion]] — Lazo de control, torque de retención activo y anti-windup.
- [[Arquitectura Dual ESP32]] — Distribución Maestro-Esclavo y comunicación en tiempo real.
- [[Protocolo UART Binario]] — Estructura de tramas seriales, CRC8 y sincronización.
- [[Glosario CDPR]] — Diccionario técnico de términos y siglas del sistema.

## 🛠️ Hardware y Recursos
- [[Especificaciones de Hardware]] — Ficha técnica consolidada de motores, poleas y controladores.
- [[Esquema de Conexiones y Pines]] — Pinout detallado de ambos ESP32, MCP23017 y TB6612FNG.
- [[Errores Conocidos y Troubleshooting]] — Guía de resolución de problemas físicos y lógicos.

## 💻 Simulación y Pruebas
- [[Simulador Python CDPR]] — Módulos en Python para visualización 3D y simulación dinámica.
- [[Plan de Pruebas de Cinemática]] — Casos de prueba para verificar el modelo matemático.

---

> [!TIP]
> Si tienes instalado el plugin **Dataview**, puedes listar todas las notas de este proyecto usando la siguiente consulta en una nota nueva:
> ```dataview
> LIST FROM #proyecto/cdpr SORT file.name ASC
> ```

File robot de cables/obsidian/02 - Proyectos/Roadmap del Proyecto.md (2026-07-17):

---
tags: [proyecto/cdpr, tipo/roadmap]
estado: en progreso
creado: 2026-07-16
---
relacionado: [[00 - MOC CDPR]], [[Robot Paralelo de Cables 6-DOF]]
---

# 🗺️ Roadmap del Proyecto - CDPR

Este documento registra los hitos alcanzados y planificados para el desarrollo, simulación y puesta en marcha del Robot Paralelo Accionado por Cables (CDPR).

---

## 🏁 Estado General del Proyecto
- [x] **Fase 1: Diseño Mecánico y Definición Geométrica**
- [x] **Fase 2: Arquitectura del Firmware Dual (MAIN + ENCODER)**
- [/] **Fase 3: Integración de Controladores Físicos y Lazo Cerrado**
- [ ] **Fase 4: Puesta en Marcha Física y Calibración**
- [ ] **Fase 5: Trayectorias Avanzadas e Interfaz Web Final**

---

## 🎯 Plan Detallado de Hitos

### Hito 1: Modelo Geométrico y Simulación Dinámica (Completado)
- [x] Definir coordenadas estáticas de las poleas (`POLE_POSITIONS`) y los anclajes de la plataforma móvil (`ANCHOR_POSITIONS`).
- [x] Desarrollar el script de simulación cinemática inversa en Python (`kinematics.py`).
- [x] Implementar simulación del comportamiento transitorio del motor DC basado en variables electromecánicas en Python (`motor_sim.py`).
- [x] Diseñar visor 3D de cables y efector en tiempo real (`visualizer.py`).

### Hito 2: Comunicación y Lecturas de Hardware (Completado)
- [x] Desarrollar firmware de lectura de encoder de 8 canales usando contadores PCNT de hardware en el ESP32 ENCODER.
- [x] Definir protocolo serial binario de comunicación bidireccional a 921600 bps.
- [x] Implementar validación de redundancia de tramas por CRC-8 Dallas/Maxim.
- [x] Crear máquina de estados lógica del robot (`STATE_INIT`, `STATE_HOMING`, `STATE_READY`, `STATE_ESTOP`, etc.).
- [x] Probar el lazo de seguridad de pérdida de comunicación UART ($50\text{ ms}$ timeout para apagar motores).

### Hito 3: Control en Lazo Cerrado e Integración de Motores (En Progreso)
- [/] Resolver conflictos de pines de arranque (*strapping pins*) en el ESP32 MAIN para evitar bloqueos del procesador al encender.
- [x] Implementar regulador PID de posición a 1 kHz en el ESP32 MAIN.
- [x] Diseñar algoritmo de torque de retención activo (`anti-holgura`) para mantener cables tensionados en el firmware.
- [ ] Implementar la interfaz I2C a 400 kHz con el expansor MCP23017 para conmutar las direcciones físicas de los puentes H TB6612FNG.
- [ ] Validar la cinemática inversa en bucle cerrado usando simulación UART por hardware (`SIMULATION_MODE=1`).

### Hito 4: Calibración y Movimiento Real (Planificado)
- [ ] Soldar pull-ups de $10\text{ k}\Omega$ en los canales de entrada analógica/digital GPI del ESP32 ENCODER para lecturas limpias de encoder.
- [ ] Calibrar el punto cero (*Homing*) tensando manualmente cada cable y reseteando los contadores acumulados de encoders.
- [ ] Ejecutar movimientos simples de traducción pura (ejes X, Y, Z de forma independiente) a velocidad controlada.
- [ ] Caracterizar la holgura del cable y la variación no lineal del radio del tambor al enrollarse.

---

## Enlaces Relacionados
- [[00 - MOC CDPR]]
- [[Robot Paralelo de Cables 6-DOF]]
- [[Especificaciones de Hardware]]
- [[Plan de Pruebas de Cinemática]]

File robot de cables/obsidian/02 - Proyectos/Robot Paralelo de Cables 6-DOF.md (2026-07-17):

---
tags: [proyecto/cdpr, tipo/proyecto]
estado: en progreso
creado: 2026-07-16
---
relacionado: [[00 - MOC CDPR]], [[Roadmap del Proyecto]], [[Bitácora de Pruebas]]
---

# Robot Paralelo de Cables 6-DOF

## Resumen del Proyecto
Este proyecto consiste en la implementación del firmware y software de simulación para un **Robot Paralelo Accionado por Cables (CDPR)** de 6 grados de libertad (X, Y, Z, Roll, Pitch, Yaw). La arquitectura lógica y de hardware se divide en dos placas **ESP32** para maximizar la velocidad de respuesta en tiempo real (lazo PID a 1 kHz) y evitar problemas de contención de pines.

---

## Conceptos Clave
- **[[Arquitectura Dual ESP32]]**: División de trabajo entre un controlador Maestro (Motores, PID, Servidor Web) y un Esclavo (PCNT Encoder Reader).
- **[[Protocolo UART Binario]]**: Interconexión serial binaria de alta velocidad (921600 bps) protegida por CRC8.
- **[[Cinematica Inversa CDPR]]**: Modelo geométrico 3D que determina la longitud teórica de cada cable dada la pose del efector final.
- **[[Control PID de Posicion]]**: Lazo cerrado de posición para controlar los motores con torque de retención activo anti-holgura.
- **[[Esquema de Conexiones y Pines]]**: Distribución física de los pines e integración del expansor MCP23017 y los drivers TB6612FNG.
- **[[Simulador Python CDPR]]**: Entorno de validación y simulación dinámica en PC.

---

## Aplicaciones Prácticas
1. **Posicionamiento Espacial de Cargas**: Simulación y movimiento de un efector final de 6-DOF en un espacio volumétrico acotado.
2. **Estudio Cinémico y Dinámico**: Ensayos de tensión de cables y control de trayectorias utilizando simulación interna en tiempo real.
3. **Plataformas de Movimiento**: Base para el desarrollo de simuladores de vuelo o cabinas interactivas.

---

## Estado y Siguiente Hito (Proyecto)
> [!NOTE]
> **Siguiente Hito**: Validar el control PID en bucle cerrado integrando los controladores de motor hardware y calificar la exactitud del cálculo cinemático en modo simulación física (`SIMULATION_MODE=1`). Ver la lista detallada en [[Roadmap del Proyecto]].

---

## Enlaces Relacionados
- [[00 - MOC CDPR]]
- [[Roadmap del Proyecto]]
- [[Especificaciones de Hardware]]
- [[Bitácora de Pruebas]]

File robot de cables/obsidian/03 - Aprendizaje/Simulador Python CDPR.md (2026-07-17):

---
tags: [proyecto/cdpr, tipo/aprendizaje]
estado: validado
creado: 2026-07-16
---
relacionado: [[00 - MOC CDPR]], [[Cinematica Inversa CDPR]], [[Plan de Pruebas de Cinemática]]
---

# Simulador Python CDPR

## Definición
Conjunto de herramientas en Python diseñadas para validar de manera interactiva la cinemática inversa, visualizar en 3D el estado del robot paralelo accionado por cables y simular dinámicamente el comportamiento de los motores en PC antes del despliegue en hardware real.

---

## Estructura de Módulos del Simulador

El directorio `python-sim/` contiene las siguientes utilidades:
1. `kinematics.py`: Módulo de cinemática inversa que calcula la longitud teórica de los 8 cables dada una pose de 6-DOF.
2. `motor_sim.py`: Simulación física del motor DC basada en ecuaciones diferenciales del sistema electromecánico:
   - Resistencia ($R = 7.5\,\Omega$), Inductancia ($L = 0.05\text{ H}$), Inercia ($J = 0.0001$), Fricción viscosa ($B = 0.0002$), Constante de torque/fuerza contraelectromotriz ($K_t = K_e = 0.08$).
3. `validation.py`: Script para interactuar por comunicación serie serializada JSON con el ESP32 MAIN y registrar datos de comportamiento.
4. `visualizer.py`: Visualización 3D del volumen del robot, postes, plataforma y tensiones relativas de los cables usando matplotlib/3D.

---

## Ejecución del Sistema de Validación y Simulación
Para correr el simulador dinámico y validar la interconexión con el firmware:

1. **Habilitar modo Simulación**:
   Define `-DSIMULATION_MODE=1` en los archivos `platformio.ini` tanto del ESP32 MAIN como de la placa ENCODER.
2. **Conexión física**:
   Une los dos ESP32 cruzando sus líneas UART y compartiendo GND (ver [[Esquema de Conexiones y Pines]]).
3. **Lanzar Script en PC**:
   Conecta el puerto USB del ESP32 MAIN a tu PC y ejecuta:
   ```bash
   python python-sim/validation.py
   ```

---

## Enlaces Relacionados
- [[00 - MOC CDPR]]
- [[Robot Paralelo de Cables 6-DOF]]
- [[Cinematica Inversa CDPR]]
- [[Esquema de Conexiones y Pines]]
- [[Plan de Pruebas de Cinemática]]

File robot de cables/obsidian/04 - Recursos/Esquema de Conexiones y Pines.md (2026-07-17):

---
tags: [proyecto/cdpr, tipo/recurso]
estado: validado
creado: 2026-07-16
---
relacionado: [[00 - MOC CDPR]], [[Arquitectura Dual ESP32]], [[Control PID de Posicion]], [[Especificaciones de Hardware]], [[Errores Conocidos y Troubleshooting]]
---

# Esquema de Conexiones y Pines

## Resumen del Hardware
El robot utiliza un expansor de pines I2C **MCP23017** de 16 bits para controlar las entradas de dirección (IN1 e IN2) de los 4 drivers de puente H de motor **TB6612FNG**. Las señales de PWM se conectan directamente a 8 GPIOs independientes del ESP32 MAIN.

---

## Conexiones I2C e Interconexión de Placas

### 1. Enlace UART Binario (Inter-ESP32)
> [!IMPORTANT]
> **Tierra Común Obligatoria**: El cable de interconexión UART entre ambos ESP32 debe tener las líneas TX/RX cruzadas y es **estrictamente obligatorio compartir la línea GND** para asegurar que el flujo de datos no se corrompa por diferencias de potencial eléctrico.

```text
[ ESP32 MAIN ]                                  [ ESP32 ENCODER ]
  GND -------------------------------------------- GND (Común Obligatorio)
  RX2 (GPIO 16) <--------------------------------- TX2 (GPIO 17) [Telemetría Encoders]
  TX2 (GPIO 17) ---------------------------------> RX2 (GPIO 16) [Consignas PWM en Simulación]
```

### 2. Canales I2C (ESP32 MAIN a MCP23017)
- **SDA**: GPIO 21 $\leftrightarrow$ Pin 13 del MCP23017
- **SCL**: GPIO 22 $\leftrightarrow$ Pin 12 del MCP23017
- **STBY (Standby Unificado de Drivers)**: GPIO 5 $\rightarrow$ Conectado a la línea `STBY` de los 4 TB6612FNG. Si se tira a `LOW`, desactiva físicamente todos los motores (función ESTOP).

---

## Asignación de Pines y Bits

### ESP32 MAIN / MOTOR (Control de Actuadores)
| Motor | Pin PWM ESP32 | Bit MCP23017 (IN1) | Bit MCP23017 (IN2) | Puerto MCP23017 |
| :--- | :--- | :--- | :--- | :--- |
| **Motor 0** | GPIO 2 | Bit 0 | Bit 1 | GPA0 (Pin 21) / GPA1 (Pin 22) |
| **Motor 1** | GPIO 12 | Bit 2 | Bit 3 | GPA2 (Pin 23) / GPA3 (Pin 24) |
| **Motor 2** | GPIO 14 | Bit 4 | Bit 5 | GPA4 (Pin 25) / GPA5 (Pin 26) |
| **Motor 3** | GPIO 23 | Bit 6 | Bit 7 | GPA6 (Pin 27) / GPA7 (Pin 28) |
| **Motor 4** | GPIO 27 | Bit 8 | Bit 9 | GPB0 (Pin 1) / GPB1 (Pin 2) |
| **Motor 5** | GPIO 18 | Bit 10 | Bit 11 | GPB2 (Pin 3) / GPB3 (Pin 4) |
| **Motor 6** | GPIO 19 | Bit 12 | Bit 13 | GPB4 (Pin 5) / GPB5 (Pin 6) |
| **Motor 7** | GPIO 25 | Bit 14 | Bit 15 | GPB6 (Pin 7) / GPB7 (Pin 8) |

> [!WARNING]
> **Riesgo de Strapping Pins**:
> - **GPIO 12 (MTDI)** es un pin de strapping. Si está a nivel `HIGH` durante el inicio del ESP32 MAIN, la tensión de la memoria flash se configurará a 1.8V en lugar de 3.3V, lo que causará un fallo de arranque en la mayoría de módulos ESP32. Asegúrese de que la entrada del TB6612FNG no mantenga un pull-up en esta línea en el encendido.
> - **GPIO 2** es otro pin de strapping (debe estar a `LOW` o flotante al bootear).

---

### ESP32 ENCODER (Lectura de Captura)
El ESP32 secundario dedica sus periféricos PCNT a la lectura rápida de los encoders:

| Motor | Canal Encoder A (GPIO) | Canal Encoder B (GPIO) | Unidad PCNT |
| :--- | :--- | :--- | :--- |
| **Motor 0** | GPIO 34 | GPIO 35 | PCNT 0 |
| **Motor 1** | GPIO 36 | GPIO 39 | PCNT 1 |
| **Motor 2** | GPIO 32 | GPIO 33 | PCNT 2 |
| **Motor 3** | GPIO 25 | GPIO 26 | PCNT 3 |
| **Motor 4** | GPIO 27 | GPIO 13 | PCNT 4 |
| **Motor 5** | GPIO 23 | GPIO 19 | PCNT 5 |
| **Motor 6** | GPIO 4 | GPIO 15 | PCNT 6 |
| **Motor 7** | GPIO 18 | GPIO 14 | PCNT 7 |

> [!IMPORTANT]
> Los pines de entrada **GPIO 34, 35, 36 y 39** en el ESP32 no disponen de resistencias de pull-up o pull-down internas por software. Si los encoders de tus motores son de colector abierto (open-drain), es estrictamente necesario soldar resistencias de pull-up externas de $10\text{ k}\Omega$ en estas líneas.

---

## Enlaces Relacionados
- [[00 - MOC CDPR]]
- [[Robot Paralelo de Cables 6-DOF]]
- [[Arquitectura Dual ESP32]]
- [[Control PID de Posicion]]
- [[Especificaciones de Hardware]]

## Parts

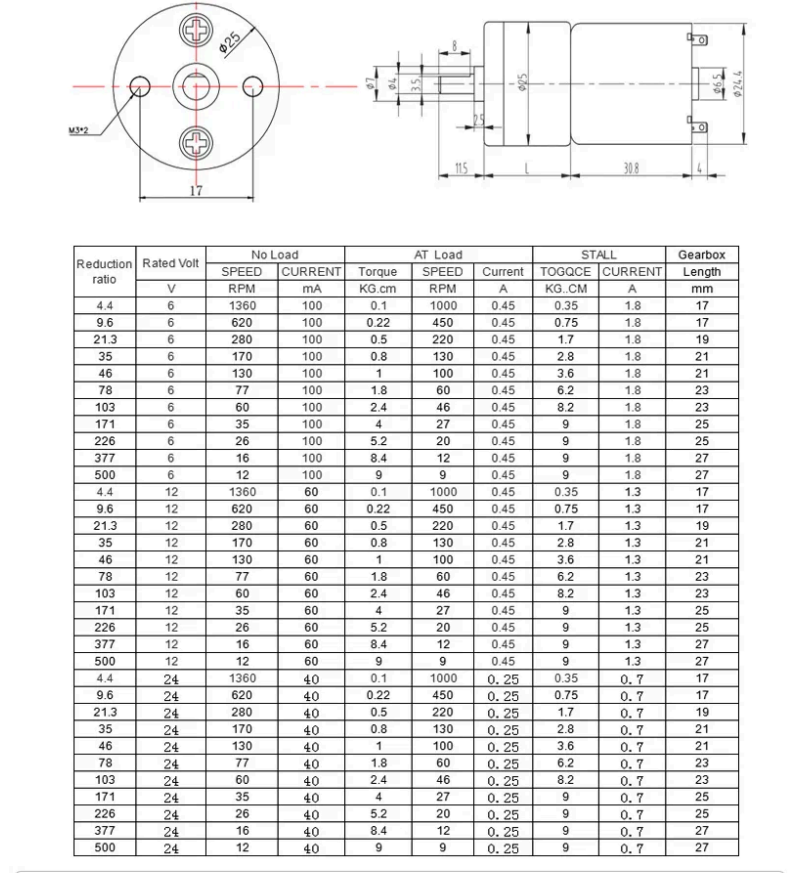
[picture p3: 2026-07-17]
robot de cables/Documentation_Parts/Documentacion_Motores/Engine_Data_Table.png

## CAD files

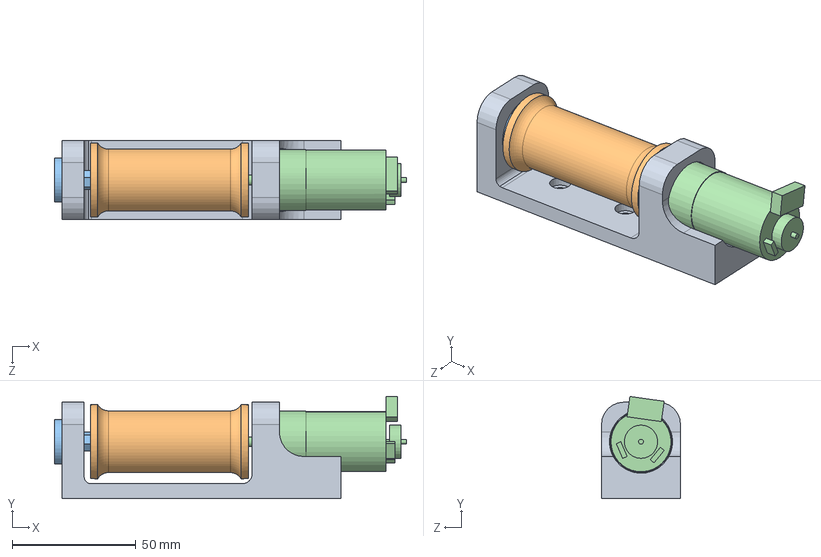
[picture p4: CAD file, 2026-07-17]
robot de cables/3d/Ensamblaje2.SLDASM
142.5 x 41.3 x 32.0 mm
Pieza4
rodillo - copia
eje
JGA25-370 DC12V350RPM.stp

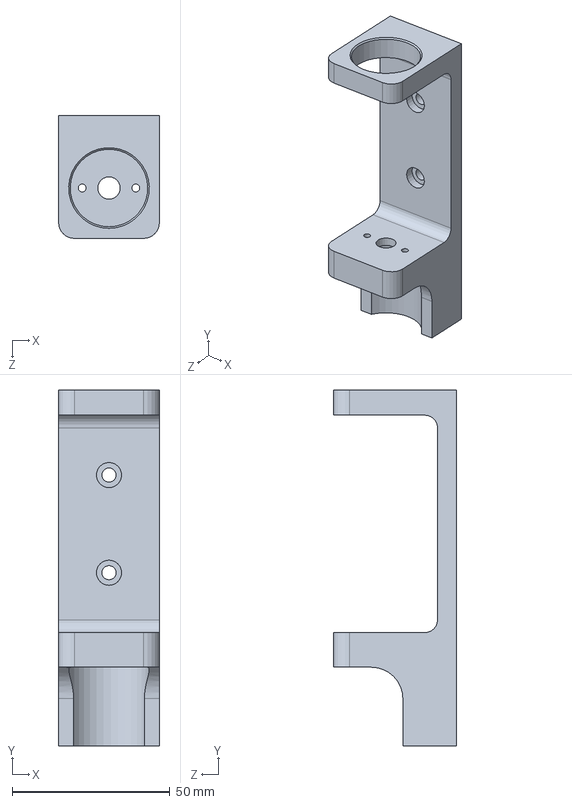
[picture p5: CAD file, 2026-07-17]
robot de cables/3d/Pieza4.SLDPRT
32.0 x 113.0 x 39.0 mm

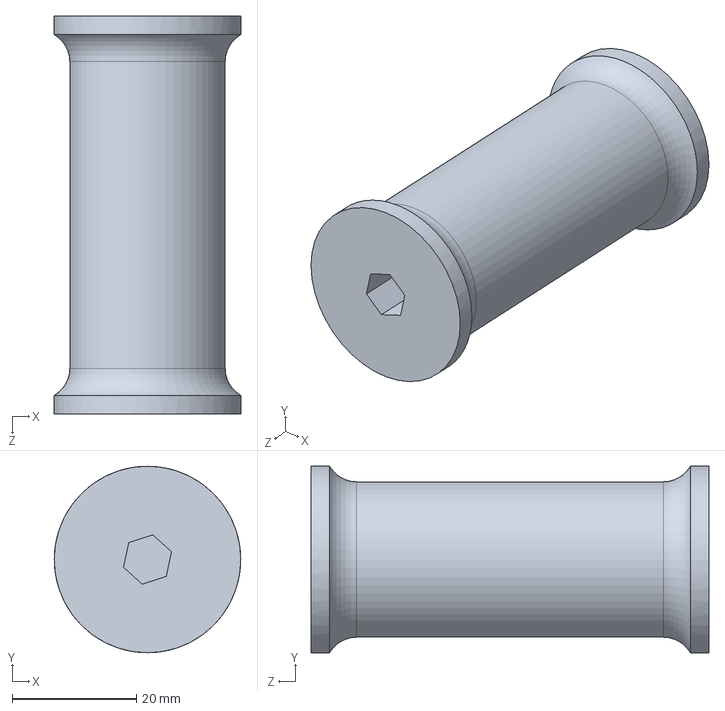
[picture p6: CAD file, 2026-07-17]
robot de cables/3d/rodillo - copia.SLDPRT
30.0 x 30.0 x 64.0 mm

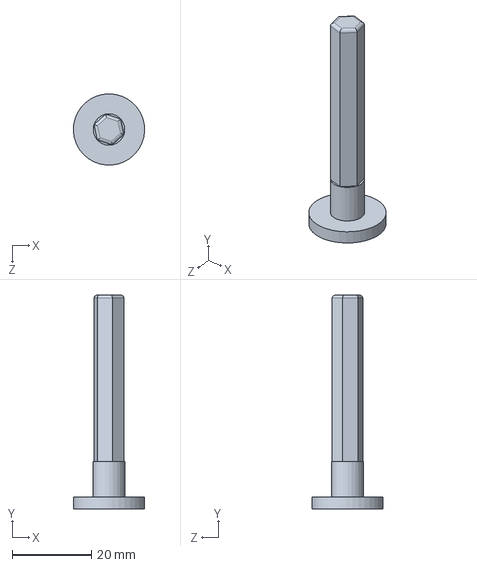
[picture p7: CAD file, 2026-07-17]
robot de cables/3d/eje.SLDPRT
18.0 x 54.0 x 18.0 mm

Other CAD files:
robot de cables/3d/Pieza4.STL

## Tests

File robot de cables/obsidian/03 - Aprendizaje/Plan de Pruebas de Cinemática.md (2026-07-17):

---
tags: [proyecto/cdpr, tipo/aprendizaje]
estado: borrador
creado: 2026-07-16
---
relacionado: [[00 - MOC CDPR]], [[Cinematica Inversa CDPR]], [[Simulador Python CDPR]]
---

# Plan de Pruebas de Cinemática

Este documento define la estrategia y los casos de prueba para validar que el modelo cinemático del robot paralelo accionado por cables (CDPR) implementado en el ESP32 coincide exactamente con el modelo matemático y la simulación interactiva de Python.

---

## 🎯 Estrategia de Validación

La validación se realiza comparando los resultados del cálculo de longitudes de cable de la función `calculateInverseKinematics` ejecutada en C++ en el ESP32 contra la función `calculate_inverse_kinematics` ejecutada en Python en el PC, para un conjunto de poses seleccionadas.

### Criterio de Aceptación
Para cada caso de prueba, la diferencia máxima absoluta entre la longitud de cada uno de los 8 cables calculada en Python y en C++ debe cumplir:
$$
\Delta L_i = |L_{\text{python}, i} - L_{\text{cpp}, i}| \le 0.001\text{ cm} \quad (10\,\mu\text{m})
$$

---

## 📋 Casos de Prueba Críticos

| ID Caso | Pose de Entrada $(x, y, z, Roll, Pitch, Yaw)$ | Propósito de la Prueba | Longitudes Teóricas Esperadas |
| :--- | :--- | :--- | :--- |
| **TC-01** | $(0.0, 0.0, 22.5, 0.0, 0.0, 0.0)$ | **Pose Central (Reposo)**: Verifica el estado inicial simétrico y alineado. | Los 8 cables deben medir exactamente la misma longitud por simetría geométrica: $31.819\text{ cm}$. |
| **TC-02** | $(0.0, 0.0, 45.0, 0.0, 0.0, 0.0)$ | **Límite Superior**: Plataforma móvil llevada al plano superior donde se encuentran las poleas fijas. | Cables muy cortos. Caso extremo para comprobar singularidades físicas del modelo matemático. |
| **TC-03** | $(10.0, -10.0, 20.0, 0.0, 0.0, 0.0)$ | **Traslación Pura Descentrada**: Movimiento lineal diagonal fuera del origen. | Longitudes asimétricas. Verifica la correcta proyección de las coordenadas de las poleas. |
| **TC-04** | $(0.0, 0.0, 22.5, 0.174, 0.0, 0.0)$ | **Rotación Pura de Roll ($10^\circ$)**: La plataforma rota alrededor del eje X. | Evalúa los términos sen/cos del Roll en la matriz de rotación $R_{zyx}$. |
| **TC-05** | $(0.0, 0.0, 22.5, 0.174, 0.174, 0.174)$ | **Rotación y Traslación Combinada**: Pose arbitraria de 6 grados de libertad. | Acoplamiento total de todas las variables trigonométricas en la matriz de rotación. |

---

## 💻 Procedimiento de Ejecución
1. Configurar los ESP32 en `SIMULATION_MODE=1`.
2. Conectar el ESP32 MAIN a la PC y abrir la consola serie para recibir las tramas de telemetría de depuración.
3. Utilizar el script `validation.py` para inyectar secuencialmente los comandos de pose correspondientes a los casos de prueba `TC-01` a `TC-05`.
4. Registrar en la [[Bitácora de Pruebas]] la salida de longitudes calculadas por el ESP32 y comparar con la simulación en Python.

---

## Enlaces Relacionados
- [[00 - MOC CDPR]]
- [[Cinematica Inversa CDPR]]
- [[Simulador Python CDPR]]
- [[Bitácora de Pruebas]]

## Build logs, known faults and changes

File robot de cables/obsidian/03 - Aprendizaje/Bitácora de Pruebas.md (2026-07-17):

---
tags: [proyecto/cdpr, tipo/bitacora]
estado: en progreso
creado: 2026-07-16
---
relacionado: [[00 - MOC CDPR]], [[Robot Paralelo de Cables 6-DOF]]
---

# 📝 Bitácora de Pruebas

Esta bitácora sirve para registrar cronológicamente cada una de las pruebas de control, cinemática y comunicación del sistema CDPR.

---

## 🪵 Registro Histórico de Ensayos

### Plantilla de Registro (Copia esto para cada nueva prueba)
```markdown
### [ID-Prueba] - [DD/MM/AAAA] - [Título de la Prueba]
- **Objetivo**: Qué se quería comprobar.
- **Cambio Realizado**: Qué se modificó en el firmware, software de simulación o hardware.
- **Resultado Obtenido**: Comportamiento observado, logs relevantes o gráficas.
- **Estado**: Exitoso / Fallido / Parcial
- **Próximos Pasos**: Tareas derivadas de este resultado.
```

---

### [PRUEBA-01] - 16/07/2026 - Validación del Lazo de Comunicación UART Binario
- **Objetivo**: Verificar que el ESP32 MAIN y el ESP32 ENCODER transmiten datos bidireccionales de manera consistente a 1 kHz (921600 bps) y sin pérdidas por corrupción de CRC8.
- **Cambio Realizado**: Configuración del bus UART hardware y parseador de tramas binarias con cálculo de Dallas/Maxim CRC-8 en ambos ESP32.
- **Resultado Obtenido**: Las tramas se reciben de forma estable. Se verificó que al interrumpir el cable de RX el Maestro entra en `STATE_ESTOP` tras 50 ms. La resincronización automática de trama funciona en menos de 5 ms ante la inyección de bytes basura inducidos manualmente.
- **Estado**: Exitoso
- **Próximos Pasos**: Verificar el lazo cerrado PID enviando lecturas simuladas desde el simulador en Python.

---

## Enlaces Relacionados
- [[00 - MOC CDPR]]
- [[Robot Paralelo de Cables 6-DOF]]
- [[Protocolo UART Binario]]
- [[Simulador Python CDPR]]

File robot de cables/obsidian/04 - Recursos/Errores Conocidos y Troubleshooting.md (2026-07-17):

---
tags: [proyecto/cdpr, tipo/recurso]
estado: validado
creado: 2026-07-16
---
relacionado: [[00 - MOC CDPR]], [[Esquema de Conexiones y Pines]], [[Control PID de Posicion]]
---

# Errores Conocidos y Troubleshooting

Guía rápida de diagnóstico para resolver fallos comunes en el sistema físico y lógico del Robot Paralelo Accionado por Cables (CDPR).

---

## 🛠️ Tabla de Síntomas, Causas y Soluciones

| Síntoma | Causa Probable | Solución |
| :--- | :--- | :--- |
| **El ESP32 MAIN entra constantemente en `STATE_ESTOP` por UART Timeout.** | 1. Pérdida física de conexión serial inter-placas.<br>2. Ausencia de tierra común (GND).<br>3. Desajuste de velocidad baudrate. | 1. Revise la continuidad del cable serial.<br>2. **Crucial**: Asegúrese de que el pin GND de ambos ESP32 esté conectado directamente entre sí.<br>3. Verifique que `INTERCONNECT_BAUD` sea `921600` en ambos firmwares. |
| **Cables flácidos (sin tensión) durante movimientos o parada.** | 1. Salida PID no alcanza a vencer fricción/gravedad.<br>2. Ausencia de torque de retención activo o umbral muy bajo. | 1. Compruebe la lógica anti-holgura en [[Control PID de Posicion]].<br>2. Si es necesario, incremente el valor de `HOLDING_TORQUE_PWM` (actualmente en 25) o sintonice la constante integral $K_i$. |
| **El ESP32 MAIN no arranca (LED indicador de encendido encendido pero sin logs en puerto serie).** | 1. Conflicto con pines de strapping en el arranque (`GPIO 12` o `GPIO 2`). | 1. Revise el [[Esquema de Conexiones y Pines]]. Compruebe que la línea `MTDI` (GPIO 12) no esté siendo forzada a HIGH por la circuitería externa al momento de energizar.<br>2. Añada una resistencia de pull-down externa si es necesario. |
| **Drift acumulativo de posición (el robot cree estar en una pose pero físicamente está desviado).** | 1. Ruido eléctrico en las señales A/B del encoder.<br>2. Falta de pull-ups en pines GPI (34, 35, 36, 39).<br>3. Variación del radio del tambor por superposición del cable. | 1. Soldar condensadores de $0.1\,\mu\text{F}$ en paralelo con las entradas de encoder para filtrar ruido de alta frecuencia.<br>2. Instalar resistencias de pull-up externas de $10\text{ k}\Omega$ en los canales del ESP32 ENCODER que usan GPIOs 34, 35, 36 y 39.<br>3. Implementar corrección matemática no lineal para el radio del tambor si el cable se enrolla sobre sí mismo. |
| **El ESP32 ENCODER se reinicia inesperadamente y causa `STATE_ESTOP` en el MAIN.** | 1. Ruido electromagnético inducido por los motores.<br>2. Caída momentánea de tensión en la línea de 5V/3.3V debido al consumo de los motores. | 1. Separe físicamente las rutas de los cables de potencia de los motores de los cables de señal de los encoders.<br>2. Instale un condensador electrolítico grande ($470\,\mu\text{F}$ o superior) cerca de la alimentación de los drivers TB6612FNG. |

---

## Enlaces Relacionados
- [[00 - MOC CDPR]]
- [[Esquema de Conexiones y Pines]]
- [[Control PID de Posicion]]
- [[Arquitectura Dual ESP32]]

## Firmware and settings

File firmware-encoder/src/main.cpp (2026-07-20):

#include <Arduino.h>
#include "Config.h"

#if !SIMULATION_MODE
#include "driver/pcnt.h"
#endif

// Identificador único de arranque generado pseudoaleatoriamente en setup()
uint8_t boot_id = 0;

// Variables de Simulación
struct SimMotor {
    float current = 0.0f;
    float omega = 0.0f;
    float angle = 0.0f;
    int32_t ticks = 0;
};
SimMotor sim_motors[8];

// =============================================================================
// CÁLCULO DE CRC8 (Dallas/Maxim 0x31)
// =============================================================================
uint8_t calculateCRC8(const uint8_t *data, size_t len) {
    uint8_t crc = 0x00;
    for (size_t i = 0; i < len; i++) {
        uint8_t inbyte = data[i];
        for (uint8_t j = 8; j; j--) {
            uint8_t mix = (crc ^ inbyte) & 0x01;
            crc >>= 1;
            if (mix) {
                crc ^= 0x8C; // Dallas/Maxim polynomial reflected
            }
            inbyte >>= 1;
        }
    }
    return crc;
}

// =============================================================================
// PARSER DE UART PARA CONSIGNAS PWM (MAIN -> SUB)
// Recibe consignas en modo simulación y modo real para aplicar a motores remotos
// =============================================================================
enum ParserState {
    STATE_SEARCH_SOF1,
    STATE_SEARCH_SOF2,
    STATE_READ_LEN,
    STATE_READ_SEQ,
    STATE_READ_PAYLOAD,
    STATE_READ_CRC
};

ParserState parser_state = STATE_SEARCH_SOF1;
uint8_t rx_buffer[32]; // Payload de 32 bytes (float[8])
int rx_index = 0;
uint32_t last_rx_byte_time = 0;
float rx_pwms[8] = {0.0f};
uint32_t last_valid_pwm_time = 0;
uint8_t rx_seq = 0;

void parseIncomingUART() {
    while (Serial2.available() > 0) {
        uint8_t c = Serial2.read();
        uint32_t now = millis();
        
        // Timeout de 5 ms por byte para resincronización ante pérdida de flujo
        if (parser_state != STATE_SEARCH_SOF1 && (now - last_rx_byte_time > 5)) {
            parser_state = STATE_SEARCH_SOF1;
        }
        last_rx_byte_time = now;
        
        switch (parser_state) {
            case STATE_SEARCH_SOF1:
                if (c == 0xCC) {
                    parser_state = STATE_SEARCH_SOF2;
                }
                break;
                
            case STATE_SEARCH_SOF2:
                if (c == 0xDD) {
                    parser_state = STATE_READ_LEN;
                } else {
                    parser_state = STATE_SEARCH_SOF1;
                }
                break;
                
            case STATE_READ_LEN:
                if (c == 0x20) {
                    parser_state = STATE_READ_SEQ;
                } else {
                    parser_state = STATE_SEARCH_SOF1;
                }
                break;
                
            case STATE_READ_SEQ:
                rx_seq = c;
                rx_index = 0;
                parser_state = STATE_READ_PAYLOAD;
                break;
                
            case STATE_READ_PAYLOAD:
                rx_buffer[rx_index++] = c;
                if (rx_index >= 32) {
                    parser_state = STATE_READ_CRC;
                }
                break;
                
            case STATE_READ_CRC:
                {
                    uint8_t rx_crc = c;
                    
                    // CRC se calcula sobre SEQ + PAYLOAD
                    uint8_t crc_data[33];
                    crc_data[0] = rx_seq;
                    memcpy(&crc_data[1], rx_buffer, 32);
                    
                    uint8_t calc_crc = calculateCRC8(crc_data, 33);
                    if (calc_crc == rx_crc) {
                        memcpy(rx_pwms, rx_buffer, 32);
                        last_valid_pwm_time = now;
                    }
                    parser_state = STATE_SEARCH_SOF1;
                }
                break;
        }
    }
}

#if SIMULATION_MODE
void simulateStep(int i, float pwm_val, float dt) {
    float v_in = (pwm_val / 255.0f) * SIM_VOLTAGE;
    
    // Ecuación diferencial del motor DC
    float di = (v_in - SIM_MOTOR_R * sim_motors[i].current - SIM_MOTOR_KE * sim_motors[i].omega) / SIM_MOTOR_L;
    sim_motors[i].current += di * dt;
    
    float torque = SIM_MOTOR_KT * sim_motors[i].current;
    float tension_load = 0.005f; // Carga de tensión constante en Nm
    float total_torque = torque - tension_load;
    
    float d_omega = (total_torque - SIM_MOTOR_B * sim_motors[i].omega) / SIM_MOTOR_J;
    sim_motors[i].omega += d_omega * dt;
    
    sim_motors[i].angle += sim_motors[i].omega * dt;
    sim_motors[i].ticks = (int32_t)(sim_motors[i].angle * TICKS_PER_REV / (2.0f * PI));
}
#endif

// =============================================================================
// INICIALIZACIÓN DE CONTADORES DE HARDWARE PCNT (Solo en modo físico)
// =============================================================================
#if !SIMULATION_MODE
void initPCNT() {
    for (int i = 0; i < 8; i++) {
        if (!MOTOR_PINS[i].is_local) continue;
        
        pcnt_config_t pcnt_config;
        pcnt_config.pulse_gpio_num = MOTOR_PINS[i].encA;
        pcnt_config.ctrl_gpio_num = MOTOR_PINS[i].encB;
        pcnt_config.channel = PCNT_CHANNEL_0;
        pcnt_config.unit = (pcnt_unit_t)MOTOR_PINS[i].pcnt_unit;
        
        pcnt_config.pos_mode = PCNT_COUNT_INC;  
        pcnt_config.neg_mode = PCNT_COUNT_DEC;  
        
        pcnt_config.lctrl_mode = PCNT_MODE_KEEP;    
        pcnt_config.hctrl_mode = PCNT_MODE_REVERSE; 
        
        pcnt_config.counter_h_lim = 32767;
        pcnt_config.counter_l_lim = -32768;
        
        pcnt_unit_config(&pcnt_config);
        
        pcnt_counter_pause((pcnt_unit_t)MOTOR_PINS[i].pcnt_unit);
        pcnt_counter_clear((pcnt_unit_t)MOTOR_PINS[i].pcnt_unit);
        pcnt_counter_resume((pcnt_unit_t)MOTOR_PINS[i].pcnt_unit);
    }
}

// Inicializa pines de dirección, PWM y STBY de motores locales (4-7)
void initLocalMotors() {
    pinMode(STBY_PIN, OUTPUT);
    digitalWrite(STBY_PIN, LOW); // Apagado por defecto

    for (int i = 0; i < 8; i++) {
        if (MOTOR_PINS[i].is_local) {
            ledcAttach(MOTOR_PINS[i].pwm, 20000, 8); // 20 kHz, 8 bits
            pinMode(MOTOR_PINS[i].dir1, OUTPUT);
            pinMode(MOTOR_PINS[i].dir2, OUTPUT);
            digitalWrite(MOTOR_PINS[i].dir1, LOW);
            digitalWrite(MOTOR_PINS[i].dir2, LOW);
        }
    }
}

// Aplica las consignas de PWM recibidas a los pines locales
void updateLocalMotors(bool timeout_active) {
    if (timeout_active) {
        digitalWrite(STBY_PIN, LOW); // Apagado de emergencia
        for (int i = 0; i < 8; i++) {
            if (MOTOR_PINS[i].is_local) {
                ledcWrite(MOTOR_PINS[i].pwm, 0);
                digitalWrite(MOTOR_PINS[i].dir1, LOW);
                digitalWrite(MOTOR_PINS[i].dir2, LOW);
            }
        }
    } else {
        digitalWrite(STBY_PIN, HIGH); // Habilitado
        for (int i = 0; i < 8; i++) {
            if (MOTOR_PINS[i].is_local) {
                float pwm_output = rx_pwms[i];
                int pwm_val = (int)abs(pwm_output);
                ledcWrite(MOTOR_PINS[i].pwm, pwm_val);
                
                if (pwm_output > 0.0f) {
                    digitalWrite(MOTOR_PINS[i].dir1, HIGH);
                    digitalWrite(MOTOR_PINS[i].dir2, LOW);
                } else if (pwm_output < 0.0f) {
                    digitalWrite(MOTOR_PINS[i].dir1, LOW);
                    digitalWrite(MOTOR_PINS[i].dir2, HIGH);
                } else {
                    digitalWrite(MOTOR_PINS[i].dir1, LOW);
                    digitalWrite(MOTOR_PINS[i].dir2, LOW);
                }
            }
        }
    }
}
#endif

// =============================================================================
// TAREA PRINCIPAL DE ADQUISICIÓN Y ENVÍO (Core 1)
// =============================================================================
void encoderTask(void *pvParameters) {
    TickType_t xLastWakeTime = xTaskGetTickCount();
    const TickType_t xFrequency = pdMS_TO_TICKS(1); // 1 ms (1 kHz exactos)
    uint8_t seq = 0;

    while (true) {
        int32_t current_ticks[8] = {0};

        // 1. Leer y parsear entrada de PWMs de forma no bloqueante
        parseIncomingUART();
        
        // 2. Determinar si hay timeout en la recepción de consignas (50 ms)
        bool timeout_active = (millis() - last_valid_pwm_time > 50);
        
        #if SIMULATION_MODE
        if (timeout_active) {
            for (int i = 0; i < 8; i++) {
                rx_pwms[i] = 0.0f;
            }
        }
        
        // Correr integración física del motor DC
        float dt = 0.001f; // 1 ms
        for (int i = 0; i < 8; i++) {
            simulateStep(i, rx_pwms[i], dt);
            current_ticks[i] = sim_motors[i].ticks;
        }
        #else
        // Aplicar PWM y direcciones físicamente a motores locales (M4-M7)
        updateLocalMotors(timeout_active);

        // Leer valores físicos locales desde contadores PCNT
        for (int i = 0; i < 8; i++) {
            if (MOTOR_PINS[i].is_local) {
                int16_t raw_count = 0;
                pcnt_get_counter_value((pcnt_unit_t)MOTOR_PINS[i].pcnt_unit, &raw_count);
                current_ticks[i] = raw_count;
            } else {
                current_ticks[i] = 0; // Motores remotos se inicializan en 0
            }
        }
        #endif

        // Empaquetar el frame ENCODER -> MAIN
        uint8_t tx_frame[38];
        tx_frame[0] = 0xAA;
        tx_frame[1] = 0xBB;
        tx_frame[2] = 0x20;
        tx_frame[3] = seq;
        tx_frame[4] = boot_id;
        
        // Serialización del payload por copia directa de memoria (Little-Endian)
        memcpy(&tx_frame[5], current_ticks, 32);
        
        // Calcular CRC8 sobre bytes [3] a [36] (seq, boot_id, payload)
        tx_frame[37] = calculateCRC8(&tx_frame[3], 34);
        
        // Enviar por UART de interconexión
        Serial2.write(tx_frame, 38);
        
        seq++;
        vTaskDelayUntil(&xLastWakeTime, xFrequency);
    }
}

void setup() {
    Serial.begin(SERIAL_BAUD);
    
    // UART2 de interconexión con MAIN
    Serial2.begin(INTERCONNECT_BAUD, SERIAL_8N1, UART_RX_PIN, UART_TX_PIN);
    
    // Generación del BOOT_ID pseudoaleatorio único
    boot_id = (uint8_t)(esp_random() % 256);
    
    Serial.print("--- CDPR SUB SLAVE INITIALIZED ---\n");
    Serial.printf("BOOT_ID asignado: 0x%02X\n", boot_id);

    #if !SIMULATION_MODE
    initPCNT();
    initLocalMotors();
    Serial.println("Hardware PCNT e I/O de motores locales inicializados.");
    #else
    Serial.println("MODO SIMULACIÓN ACTIVO (Slave): Simulando física del motor por software.");
    #endif

    // Crear la tarea periódica a 1 kHz fijada al Core 1
    xTaskCreatePinnedToCore(
        encoderTask,
        "EncoderTask",
        4096,
        NULL,
        9, // Alta prioridad
        NULL,
        1
    );
}

void loop() {
    // El loop queda libre para tareas secundarias o de debug
    delay(100);
}

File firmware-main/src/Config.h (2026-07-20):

#ifndef CONFIG_H
#define CONFIG_H

#include <Arduino.h>

// =============================================================================
// MODO SIMULACIÓN Y CONFIGURACIÓN GENERAL
// =============================================================================
#ifndef SIMULATION_MODE
#define SIMULATION_MODE 1
#endif

#define SERIAL_BAUD 115200
#define CONTROL_LOOP_HZ 1000 // 1 kHz
#define INTERCONNECT_BAUD 921600

// =============================================================================
// INTERCONEXIÓN UART (Hacia el ESP32 SUB)
// =============================================================================
#define UART_RX_PIN 16
#define UART_TX_PIN 17

// =============================================================================
// RED WI-FI (MODO PUNTO DE ACCESO - AP)
// =============================================================================
#define AP_SSID "CDPR_Cable_Robot"
#define AP_PASSWORD "12345678"
#define AP_CHANNEL 1
#define AP_MAX_CONN 4

// =============================================================================
// PINES DE SEGURIDAD LOCALES (ESP32 MAIN)
// =============================================================================
#define STBY_PIN 5 // Se tira a LOW en ESTOP para apagar los puentes H locales en hardware

// =============================================================================
// GEOMETRÍA DEL ROBOT (Unidades en centímetros)
// =============================================================================
struct Vector3D {
    float x;
    float y;
    float z;
};

const Vector3D POLE_POSITIONS[8] = {
    {-22.5f, -21.0f, 45.0f}, // Cable 0 (Esquina 1, Polea A)
    {-21.0f, -22.5f, 45.0f}, // Cable 1 (Esquina 1, Polea B)
    { 21.0f, -22.5f, 45.0f}, // Cable 2 (Esquina 2, Polea A)
    { 22.5f, -21.0f, 45.0f}, // Cable 3 (Esquina 2, Polea B)
    { 22.5f,  21.0f, 45.0f}, // Cable 4 (Esquina 3, Polea A)
    { 21.0f,  22.5f, 45.0f}, // Cable 5 (Esquina 3, Polea B)
    {-21.0f,  22.5f, 45.0f}, // Cable 6 (Esquina 4, Polea A)
    {-22.5f,  21.0f, 45.0f}  // Cable 7 (Esquina 4, Polea B)
};

const Vector3D ANCHOR_POSITIONS[8] = {
    {-5.0f, -4.0f, 0.0f}, // Cable 0
    {-4.0f, -5.0f, 0.0f}, // Cable 1
    { 4.0f, -5.0f, 0.0f}, // Cable 2
    { 5.0f, -4.0f, 0.0f}, // Cable 3
    { 5.0f,  4.0f, 0.0f}, // Cable 4
    { 4.0f,  5.0f, 0.0f}, // Cable 5
    {-4.0f,  5.0f, 0.0f}, // Cable 6
    {-5.0f,  4.0f, 0.0f}  // Cable 7
};

const Vector3D DEFAULT_START_POSE_POS = {0.0f, 0.0f, 22.5f};
const Vector3D DEFAULT_START_POSE_ROT = {0.0f, 0.0f, 0.0f};

// =============================================================================
// ASIGNACIÓN DE PINES GPIO (ESP32 MAIN)
// =============================================================================
struct MotorPins {
    bool is_local;       // True si el motor se controla/lee en esta placa
    uint8_t pwm;         // Pin de PWM
    uint8_t dir1;        // Pin IN1
    uint8_t dir2;        // Pin IN2
    uint8_t encA;        // Pin Encoder Canal A
    uint8_t encB;        // Pin Encoder Canal B
    int pcnt_unit;       // Unidad PCNT (solo local)
};

const MotorPins MOTOR_PINS[8] = {
    // Local?, PWM, DIR1, DIR2, EncA, EncB, PCNT_Unit
    { true,  2,  4, 15, 34, 35, 0 },  // Motor 0 (Local M0)
    { true, 12, 13, 14, 36, 39, 1 },  // Motor 1 (Local M1)
    { true, 25, 26, 27, 32, 33, 2 },  // Motor 2 (Local M2)
    { true, 18, 19, 23, 21, 22, 3 },  // Motor 3 (Local M3)
    { false, 0,  0,  0,  0,  0, -1 },  // Motor 4 (Remoto)
    { false, 0,  0,  0,  0,  0, -1 },  // Motor 5 (Remoto)
    { false, 0,  0,  0,  0,  0, -1 },  // Motor 6 (Remoto)
    { false, 0,  0,  0,  0,  0, -1 }   // Motor 7 (Remoto)
};

// =============================================================================
// PARÁMETROS DE LOS MOTORES Y REDUCCIÓN
// =============================================================================
const float GEAR_RATIO = 45.0f;
const float ENCODER_PPR = 11.0f;
const float DRUM_RADIUS_CM = 1.0f;
const float TICKS_PER_REV = ENCODER_PPR * 4.0f * GEAR_RATIO;
const float TICKS_PER_CM = TICKS_PER_REV / (2.0f * PI * DRUM_RADIUS_CM);

// Constantes físicas del motor DC para simulación interna
const float SIM_MOTOR_R = 7.5f;
const float SIM_MOTOR_L = 0.05f;
const float SIM_MOTOR_KT = 0.08f;
const float SIM_MOTOR_KE = 0.08f;
const float SIM_MOTOR_J = 0.0001f;
const float SIM_MOTOR_B = 0.0002f;
const float SIM_VOLTAGE = 12.0f;

// =============================================================================
// PARÁMETROS PID
// =============================================================================
const float PID_KP = 8.5f;
const float PID_KI = 0.1f;
const float PID_KD = 0.4f;
const float PID_MAX_PWM = 255.0f;
const float PID_MIN_PWM = -255.0f;
const float PID_INTEGRAL_LIMIT = 50.0f;

// Pre-tensión en reposo
const int HOLDING_TORQUE_PWM = 25;

#endif // CONFIG_H

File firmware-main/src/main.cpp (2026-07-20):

#include <Arduino.h>
#include <ArduinoJson.h>
#include <Wire.h>
#include <WiFi.h>
#include "Config.h"
#include "SystemState.h"
#include "Kinematics.h"
#include "MotorController.h"
#include "Globals.h"
#include "WebInterface.h"

#if !SIMULATION_MODE
#include "driver/pcnt.h"
#endif

// =============================================================================
// VARIABLES GLOBALES DE UART Y PROTECCIÓN
// =============================================================================
volatile int32_t uart_raw_ticks[8] = {0};
volatile uint8_t uart_boot_id = 0;
volatile uint32_t last_valid_frame_time = 0;
uint32_t dropped_frames = 0;

uint8_t active_boot_id = 0;
bool boot_id_initialized = false;
portMUX_TYPE uartMux = portMUX_INITIALIZER_UNLOCKED;

// =============================================================================
// CÁLCULO DE CRC8 (Dallas/Maxim 0x31)
// =============================================================================
uint8_t calculateCRC8(const uint8_t *data, size_t len) {
    uint8_t crc = 0x00;
    for (size_t i = 0; i < len; i++) {
        uint8_t inbyte = data[i];
        for (uint8_t j = 8; j; j--) {
            uint8_t mix = (crc ^ inbyte) & 0x01;
            crc >>= 1;
            if (mix) {
                crc ^= 0x8C; // Polinomio Dallas/Maxim reflejado
            }
            inbyte >>= 1;
        }
    }
    return crc;
}

// =============================================================================
// TRANSMISIÓN DE PWM Y DIRECCIÓN AL ESP32 SUB (Motores 4 a 7)
// =============================================================================
void transmitPWMToEncoder() {
    static uint8_t tx_seq = 0;
    uint8_t tx_frame[37];
    tx_frame[0] = 0xCC;
    tx_frame[1] = 0xDD;
    tx_frame[2] = 0x20;
    tx_frame[3] = tx_seq;
    
    float pwms[8];
    for (int i = 0; i < 8; i++) {
        pwms[i] = (float)motors[i].getPWM();
    }
    
    // Serializar por copia directa de memoria (Little-Endian)
    memcpy(&tx_frame[4], pwms, 32);
    
    // CRC se calcula sobre SEQ + PAYLOAD (33 bytes)
    tx_frame[36] = calculateCRC8(&tx_frame[3], 33);
    
    Serial2.write(tx_frame, 37);
    tx_seq++;
}

// =============================================================================
// PARSER NO BLOQUEANTE DE TELEMETRÍA (ENCODER -> MAIN)
// =============================================================================
enum ParserState {
    STATE_SEARCH_SOF1,
    STATE_SEARCH_SOF2,
    STATE_READ_LEN,
    STATE_READ_SEQ,
    STATE_READ_BOOT_ID,
    STATE_READ_PAYLOAD,
    STATE_READ_CRC
};

ParserState parser_state = STATE_SEARCH_SOF1;
uint8_t rx_buffer[32];
int rx_index = 0;
uint32_t last_rx_byte_time = 0;
uint8_t rx_seq = 0;
uint8_t rx_boot_id = 0;

bool has_prev_seq = false;
uint8_t prev_seq = 0;

void parseIncomingUART() {
    while (Serial2.available() > 0) {
        uint8_t c = Serial2.read();
        uint32_t now = millis();
        
        // Timeout de 5 ms por byte para resincronización automática
        if (parser_state != STATE_SEARCH_SOF1 && (now - last_rx_byte_time > 5)) {
            parser_state = STATE_SEARCH_SOF1;
        }
        last_rx_byte_time = now;
        
        switch (parser_state) {
            case STATE_SEARCH_SOF1:
                if (c == 0xAA) {
                    parser_state = STATE_SEARCH_SOF2;
                }
                break;
                
            case STATE_SEARCH_SOF2:
                if (c == 0xBB) {
                    parser_state = STATE_READ_LEN;
                } else {
                    parser_state = STATE_SEARCH_SOF1;
                }
                break;
                
            case STATE_READ_LEN:
                if (c == 0x20) {
                    parser_state = STATE_READ_SEQ;
                } else {
                    parser_state = STATE_SEARCH_SOF1;
                }
                break;
                
            case STATE_READ_SEQ:
                rx_seq = c;
                parser_state = STATE_READ_BOOT_ID;
                break;
                
            case STATE_READ_BOOT_ID:
                rx_boot_id = c;
                rx_index = 0;
                parser_state = STATE_READ_PAYLOAD;
                break;
                
            case STATE_READ_PAYLOAD:
                rx_buffer[rx_index++] = c;
                if (rx_index >= 32) {
                    parser_state = STATE_READ_CRC;
                }
                break;
                
            case STATE_READ_CRC:
                {
                    uint8_t rx_crc = c;
                    
                    // CRC se calcula sobre SEQ + BOOT_ID + PAYLOAD (34 bytes)
                    uint8_t crc_data[34];
                    crc_data[0] = rx_seq;
                    crc_data[1] = rx_boot_id;
                    memcpy(&crc_data[2], rx_buffer, 32);
                    
                    uint8_t calc_crc = calculateCRC8(crc_data, 34);
                    if (calc_crc == rx_crc) {
                        // Sección crítica rápida para actualizar valores globales
                        portENTER_CRITICAL(&uartMux);
                        int32_t rx_ticks[8];
                        memcpy(rx_ticks, rx_buffer, 32);
                        #if SIMULATION_MODE
                        // En modo simulación copiamos los 8 encoders desde el modelo físico del esclavo
                        for (int i = 0; i < 8; i++) {
                            uart_raw_ticks[i] = rx_ticks[i];
                        }
                        #else
                        // En modo real, los encoders 0-3 son leídos localmente por PCNT en MAIN.
                        // Solo copiamos los encoders remotos 4-7 recibidos por UART.
                        for (int i = 4; i < 8; i++) {
                            uart_raw_ticks[i] = rx_ticks[i];
                        }
                        #endif
                        uart_boot_id = rx_boot_id;
                        last_valid_frame_time = now;
                        portEXIT_CRITICAL(&uartMux);
                        
                        // Control de frames perdidos
                        if (has_prev_seq) {
                            uint8_t expected_seq = prev_seq + 1;
                            if (rx_seq != expected_seq) {
                                int diff = (rx_seq >= expected_seq) ? (rx_seq - expected_seq) : (256 - expected_seq + rx_seq);
                                dropped_frames += diff;
                            }
                        }
                        prev_seq = rx_seq;
                        has_prev_seq = true;
                    }
                    parser_state = STATE_SEARCH_SOF1;
                }
                break;
        }
    }
}
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

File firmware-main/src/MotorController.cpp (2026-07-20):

#include "MotorController.h"
#include "Globals.h"

MotorController::MotorController() 
    : id(-1), raw_ticks(0), tick_offset(0), target_ticks(0),
      integral(0.0f), last_error(0.0f), pwm_output(0.0f) {
}

void MotorController::begin(int motor_id) {
    id = motor_id;
    pins = MOTOR_PINS[motor_id];
    
#if !SIMULATION_MODE
    if (pins.is_local) {
        // Configurar PWM por hardware usando LEDC
        ledcAttach(pins.pwm, 20000, 8); // Pin, 20 kHz, 8 bits
        pinMode(pins.dir1, OUTPUT);
        pinMode(pins.dir2, OUTPUT);
        digitalWrite(pins.dir1, LOW);
        digitalWrite(pins.dir2, LOW);
    }
#endif

    raw_ticks = 0;
    tick_offset = 0;
    target_ticks = 0;
    integral = 0.0f;
    last_error = 0.0f;
    pwm_output = 0.0f;
}

void MotorController::setRawTicks(int32_t ticks) {
    raw_ticks = ticks;
}

void MotorController::setTargetPosition(float length_cm) {
    setTargetTicks((int32_t)(length_cm * TICKS_PER_CM));
}

void MotorController::setTargetTicks(int32_t ticks) {
    target_ticks = ticks;
}

void MotorController::resetEncoderLocal() {
    tick_offset = raw_ticks;
}

int32_t MotorController::getCurrentTicks() {
    return raw_ticks - tick_offset;
}

float MotorController::getCurrentLengthCm() {
    return (float)getCurrentTicks() / TICKS_PER_CM;
}

void MotorController::update(float dt) {
    // Lazo PID de Posición
    float error = (float)(target_ticks - getCurrentTicks());
    
    // Término Integral con anti-windup
    integral += error * dt;
    integral = constrain(integral, -PID_INTEGRAL_LIMIT, PID_INTEGRAL_LIMIT);
    
    // Término Derivativo
    float derivative = (error - last_error) / dt;
    last_error = error;
    
    // Señal PID
    float pid_signal = (PID_KP * error) + (PID_KI * integral) + (PID_KD * derivative);
    
    // LÓGICA DE TORQUE DE RETENCIÓN ACTIVO (ANTI-HOLGURA)
    if (pid_signal > 0.0f) {
        if (pid_signal < (float)HOLDING_TORQUE_PWM) {
            pid_signal = (float)HOLDING_TORQUE_PWM;
        }
    } else {
        if (abs(error) < 50) { // Cerca del target (aprox 1.5mm)
            pid_signal = (float)HOLDING_TORQUE_PWM;
        }
    }

    // Limitador de PWM
    pwm_output = constrain(pid_signal, PID_MIN_PWM, PID_MAX_PWM);

#if !SIMULATION_MODE
    if (pins.is_local) {
        int pwm_val = (int)abs(pwm_output);
        if (current_state == STATE_ESTOP) {
            ledcWrite(pins.pwm, 0);
            digitalWrite(pins.dir1, LOW);
            digitalWrite(pins.dir2, LOW);
        } else {
            ledcWrite(pins.pwm, pwm_val);
            if (pwm_output > 0.0f) {
                // Giro adelante: IN1 = HIGH, IN2 = LOW
                digitalWrite(pins.dir1, HIGH);
                digitalWrite(pins.dir2, LOW);
            } else if (pwm_output < 0.0f) {
                // Giro atrás: IN1 = LOW, IN2 = HIGH
                digitalWrite(pins.dir1, LOW);
                digitalWrite(pins.dir2, HIGH);
            } else {
                // Freno activo (Short brake): IN1 = LOW, IN2 = LOW
                digitalWrite(pins.dir1, LOW);
                digitalWrite(pins.dir2, LOW);
            }
        }
    }
#endif
}

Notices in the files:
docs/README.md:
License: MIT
